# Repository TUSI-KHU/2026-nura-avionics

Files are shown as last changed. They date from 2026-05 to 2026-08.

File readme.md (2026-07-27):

# 2026 NURA Avionics

Teensy 4.1 flight-computer firmware for the 2026 NURA rocket avionics stack.

The current codebase is built around a small cooperative scheduler, explicit state stores, hardware abstraction layers, and a lightweight LoRa telemetry/control protocol. It is still an active integration project: sensor acquisition, LoRa protocol work, mock telemetry, and ground-side receiver tests are in the repository, while flight rules, logging outputs, and final hardware validation are still being tightened.

## Architecture

2026 NURA avionics firmware architecture

Runtime flow:

1. `src/main.cpp` forwards Arduino `setup()` and `loop()` to `FlightControllerApp`.
2. `FlightControllerApp` owns config, state stores, HAL objects, mission tasks, sensor tasks, and the scheduler.
3. `Scheduler` runs fixed task objects cooperatively according to each task's `periodMs()`.
4. Sensor tasks update focused state structs.
5. Mission tasks consume those states for watchdog, FSM, telemetry, and logging behavior.
6. HAL classes are the only layer that should talk directly to board pins, buses, radios, and sensor libraries.

Production task order:

```text
IMUTask -> HighGImuTask -> MagnetometerTask -> BarometerTask -> GNSSTask -> WatchdogTask -> FSMTask -> FlightLogTask -> TelemetryTask -> LoggerTask
```

Mock telemetry task order:

```text
MockTelemetrySourceTask -> WatchdogTask -> FSMTask -> FlightLogTask -> TelemetryTask -> LoggerTask
```

## Current Firmware Scope

- Board target: Teensy 4.1 with Arduino framework through PlatformIO.
- Low-g IMU path: `LSM6DSO32HAL` -> `IMUTask` -> `ImuState`.
- Barometer path: `MPL3115A2HAL` -> `BarometerTask` -> `TelemetryState`.
- GNSS path: `UbloxM6GNSSHAL` -> `GNSSTask` -> `GpsState`.
- High-g IMU path: `H3LIS331DLHAL` -> `HighGImuTask` -> `HighGImuState`.
- Magnetometer path: `LIS3MDLHAL` -> `MagnetometerTask` -> `MagnetometerState`.
- LoRa path: `Sx127xLoRaHAL` plus `TelemetryTask`, targeting the SparkFun
  SPX-18572 / E19-915M30S SX1276 1 W breakout.
- Protocol: fixed-length authenticated NURA V2 Lite frames in `protocol/include/nura_protocol_v1_lite.h`.
- Flight logging: U3 program flash primary plus microSD mirror through `FlightLogTask`, with `.NLG` parsing tools under `log_parser/`.
- Mock path: `MockFlightDataHAL` and `MockTelemetrySourceTask` feed deterministic telemetry for bench protocol tests.

Additional sensor HALs and sketches remain under `src/hal` and `sensor_test` for isolated hardware bring-up.

## LoRa Protocol

The active protocol is documented in `documents/nura_lora_packet_protocol_v1.md`.

V2 Lite keeps only three message classes:

| Message | Direction | Purpose |
| --- | --- | --- |
| `FAST_TLM` | avionics -> ground | high-rate pressure delta, low-g IMU, gyro, battery, status word |
| `GPS_TLM` | avionics -> ground | slower GNSS recovery/navigation telemetry |
| `CONTROL` | bidirectional | uplink commands and downlink ACK responses |

Nominal application rates:

```text
FAST_TLM: 5 Hz
GPS_TLM: 1 Hz
CONTROL: on demand, ACK has priority over telemetry
```

Flight radio defaults currently target the SparkFun SX1276 1 W breakout at
922.3 MHz. `NURA_DEV_SX1278` switches development builds toward the legacy
SX1278/Ra-01 433 MHz bench setup.

## Repository Layout

```text
src/app/        composition root and app configuration
src/core/       scheduler, task API, logger, recoverable-task policy
src/hal/        board, bus, sensor, radio, panic, and log-output adapters
src/sensors/    sensor acquisition tasks
src/missions/   FSM, watchdog, telemetry, logger, and mock source tasks
src/state/      small shared state stores
protocol/       shared NURA V2 Lite authenticated frame codec header
log_parser/     host-side .NLG binary flight-log parser
sender/         standalone avionics-side LoRa protocol test firmware
receiver/       standalone ground-side LoRa protocol test firmware and pair-test tool
test/           embedded diagnostics, replay tests, and host-side checks
documents/      protocol, requirements, schedule exports, and architecture assets
```

## PlatformIO Environments

| Environment | Purpose |
| --- | --- |
| `main` | Teensy 4.1 firmware with the SX1276 breakout |
| `debug` | SX1276 breakout firmware with verbose logging |
| `debug_lora_autoflow` | bench-only SX1276 debug; automatic `SAFE -> ARMED -> LAUNCH`, then hold |
| `main_no_lora` | full application with the radio disabled |
| `debug_no_lora` | verbose application with the radio disabled |

Common commands:

```bash
pio run -e main
pio run -e debug
pio run -e debug_lora_autoflow
pio run -e main_no_lora
pio run -e debug_no_lora
```

`debug_lora_autoflow` is a bench-only build. It inherits the SparkFun
SPX-18572/E19-915M30S SX1276 path, limits the configured radio drive to 2 dBm,
and allows radio-init failure for wiring diagnostics. The FSM synthesizes
`SAFE -> ARMED -> LAUNCH` and then holds at `LAUNCH`; do not use it for flight
and do not connect pyro hardware.

Upload and monitor:

```bash
pio run -e build -t upload
pio device monitor -b 115200
```

The root PlatformIO environments use a custom Teensy upload command that retries
the loader after the common first soft-reboot write failure, so uploads should
work through the normal `pio run ... -t upload` path.

Standalone sender/receiver builds:

```bash
pio run -d sender
pio run -d receiver
```

Two-board LoRa protocol test:

```bash
python3 receiver/tools/run_pair_test.py --duration 20
```

## Development Agreements

Use the shared schedule sheet as the source of truth for deadlines and team coordination. The current firmware direction follows these working agreements:

- Build each hardware path through `HAL -> Task -> State`, then integrate it into the flight app.
- Verify individual sensors with Arduino/PlatformIO sketches before relying on them in the flight controller.
- Keep LoRa as a lossy telemetry and control link, not as the primary raw-data recorder.
- Store high-rate raw flight data locally through U3 program flash and the microSD mirror.
- Validate changes through unit tests, mock tests, and full hardware tests before treating them as flight-ready.
- Keep the ground station decoder aligned with `protocol/include/nura_protocol_v1_lite.h`.

## Safety Notes

- `CONTROL` commands request actions; packet parsing must not directly energize actuators.
- Emergency recovery deployment must remain deduplicated, authenticated, ACKed, and routed through mission logic.
- Frequency, output power, antenna gain, duty cycle, and final channel plan must be checked against competition rules and Korean radio requirements before flight.
- The current code is integration firmware, not a completed flight-certified avionics release.

## License

This project is licensed under the Apache License 2.0. Third-party libraries retain their own licenses.

This repository contains experimental avionics software and documentation. It is provided without warranty and must be independently reviewed, tested, and validated before any flight or safety-critical use.

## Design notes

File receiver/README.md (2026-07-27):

# NURA LoRa Receiver

Ground-side Teensy 4.1 receiver for authenticated NURA V2 Lite telemetry.

Use the `sx1276_ground` environment for the 922.3 MHz SX1276 ground radio.
The default `teensy41` environment remains the 433 MHz development setup.
The SX1276 ground environment fixes the SPI bus to MODE0; automatic mode
probing remains limited to the development environment.
The standalone ground wiring is `CS=10`, `RESET=9`, `DIO0=2`, `RXEN=4`, and
`TXEN=3`; it is intentionally independent of the flight-computer pin map.
The receive-only SX1276 environment drives `RXEN=HIGH` and `TXEN=LOW`. This
polarity is a bench assumption that must be checked against the module
datasheet before enabling ground uplink transmission.

The implementation follows `documents/nura_lora_packet_protocol_v1.md` and the shared protocol header in `protocol/include/nura_protocol_v1_lite.h`.

Default firmware behavior:

1. Decodes FAST_TLM, GPS_TLM, and CONTROL/ACK frames.
2. Prints real avionics sensor telemetry with engineering units:
   - FAST: flight state, status word, pressure delta, low-g acceleration, gyro, battery, health bits, RSSI/SNR.
   - GPS: fix, latitude/longitude, altitude, speed, course, HDOP, satellites, age, RSSI/SNR.
3. Does not transmit recovery/control commands.

Pair-test-only behavior is available in the `pair_test` environment. That build defines `NURA_RECEIVER_AUTO_COMMAND_TEST` and automatically sends FORCE_DEPLOY_RECOVERY followed by the deprecated abort command check. Do not use that environment with flight hardware unless the recovery output path is intentionally inhibited for a bench test.

The Arduino gateway must remain a dumb raw-byte bridge. All decoding and command logic belongs here or in the GCS process.

Build receive-only ground station firmware with:

```sh
pio run -d receiver -e teensy41
```

Upload and monitor receive-only firmware with:

```sh
pio run -d receiver -e teensy41 -t upload
pio device monitor -d receiver -b 115200
```

Two-board protocol test with automatic bench commands:

```sh
python3 receiver/tools/run_pair_test.py --duration 20
```

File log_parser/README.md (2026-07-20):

# NURA Log Parser

`parse_nlg.py` converts NURA binary flight logs into readable CSV and JSON
files. It auto-detects the preallocated microSD block journal, a raw W25Q128
flash dump, or a plain legacy `.NLG` frame stream.

## Usage

```bash
python3 log_parser/parse_nlg.py analysis/program_flash_NURA_LOG_FL008_NLG_20260530_145006.NLG
```

By default it creates `<input_stem>_parsed/` beside the input file. Use
`--out-dir` to choose the destination:

```bash
python3 log_parser/parse_nlg.py input.NLG --out-dir analysis/parsed_log
```

## Outputs

- `frames.csv`: every frame in sequence order, with decoded fields and units.
- `frames.json`: the same decoded frames as JSON.
- `fast_sample.csv`: high-rate IMU/barometer/state samples.
- `slow_sample.csv`: GPS/magnetometer/barometer fault counters.
- `event.csv`: boot, state transition, ground stop, and storage fault events.
- `decision.csv`: state-machine decision traces when present.
- `summary.json`: frame count, sequence range, timestamp range, and output paths.

The parser verifies frame magic, version, payload length, maximum frame size, and
CRC16-CCITT before writing decoded output. For current SD logs it first verifies
the 512-byte block session, sequence and CRC fields. For QSPI dumps it verifies
the 4 KiB sector and 256-byte page headers before reconstructing the logical
frame stream.

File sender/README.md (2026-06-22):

# NURA LoRa V2 Sender Bench Emulator

This folder is reserved for the avionics-side LoRa sender implementation.

The implementation follows `documents/nura_lora_packet_protocol_v1.md` and the shared protocol header in `protocol/include/nura_protocol_v1_lite.h`.

Current firmware behavior:

1. Sends synthetic FAST_TLM at 5 Hz.
2. Sends synthetic GPS_TLM at 1 Hz.
3. Receives CONTROL/CMD.
4. Authenticates and deduplicates commands.
5. Sends CONTROL/ACK for FORCE_DEPLOY_RECOVERY and ABORT_PROPULSION_DEPRECATED.
6. Skips telemetry whenever ACK has priority.

Do not transmit raw C++ structs directly. Encode every integer field explicitly as little-endian bytes.

Build with:

```sh
pio run -d sender
```

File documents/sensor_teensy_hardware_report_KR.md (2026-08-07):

# NURA 2026 센서 및 Teensy 하드웨어 정리 보고서

작성일: 2026-06-26  
대상 코드 기준: `include/board_pinmap.h`, `include/nura_constants.h`, `src/hal/*`, `platformio.ini`, `documents/pinmap_summary.txt`

> 이 문서는 부품 데이터시트/공식 가이드와 현재 펌웨어 핀맵을 대조한 하드웨어 정리 보고서이다. 비행 승인 문서가 아니며, PCB 리비전/실물 회로/커넥터 방향/전원 레일/납땜 상태는 별도 검증이 필요하다.

## 1. 현재 프로젝트 하드웨어 요약

| 분류 | 부품 / 모듈 | 프로젝트 역할 | 현재 인터페이스 | 현재 핀 |
| --- | --- | --- | --- | --- |
| MCU | Teensy 4.1 | 비행 컴퓨터 | USB, GPIO, SPI, I2C, UART, ADC, SDIO/QSPI | PlatformIO `teensy41` |
| 저-g IMU | LSM6DSO32 / LSM6DSOX | 주 IMU, 가속도/자이로 | SPI0 | MOSI D11, MISO D12, SCK D13, CS D10 |
| 고-g 가속도계 | H3LIS331DL | 발사/충격/고가속 로깅 후보 | SPI0 | MOSI D11, MISO D12, SCK D13, CS D0 |
| 자기계 | LIS3MDL | 자기장/방위 후보 | I2C1 | SDA1 D17, SCL1 D16, 주소 `0x1C` |
| 기압계 | MPL3115A2 | 고도/압력 | I2C0 | SDA0 D18, SCL0 D19, 주소 `0x60` |
| GNSS | u-blox M6 / NEO-6M 계열 | 위치/시간/회수 지원 | UART Serial3 | GPS TX -> D15/RX3, GPS RX -> D14/TX3, 9600 baud |
| 비행 LoRa | SparkFun SPX-18572 / E19-915M30S SX1276 1W | 비행체 텔레메트리 | SPI1 + DIO0/RXE/TXE | MISO1 D1, MOSI1 D26, SCK1 D27, NSS D9, RST D24, DIO0 D32, RXE D30, TXE D31 |
| 지상/개발 LoRa | SparkFun SPX-18572 / E19-915M30S SX1276 1W | 지상 수신/개발 테스트 | SPI1 + DIO0/RXE/TXE | 동일 922.3 MHz 핀맵 |
| 전압 센스 | 3S 배터리 분압 | 배터리 전압 텔레메트리 | ADC | D22, 분압비 5.545 |
| 저장장치 | Teensy 내장 microSD | 비행 로그 미러 | SDIO | `BUILTIN_SDCARD` |
| 저장장치 | W25Q128 QSPI NOR flash 후보 | 온보드 로그/검증 저장 | Teensy 4.1 하단 QSPI pads | 16 MB / 128 Mbit 후보 |
| 알림 | Buzzer, LED | 상태/오류 피드백 | GPIO/PWM | Buzzer D2, LED2 D33 |

중요: 현재 소스의 기준은 `include/board_pinmap.h`와 `documents/pinmap_summary.txt`이다. 현재 Pyro 1은 gpio1 D28/gpio2 D29/sense D25, Pyro 2는 gpio1 D38/gpio2 D35/sense D41, 배터리 전압 센스는 D22로 서로 충돌하지 않는다.

## 2. Teensy 4.1

### 핵심 특징

- MCU: NXP i.MX RT1062, 600 MHz급 ARM Cortex-M7 계열 보드.
- I/O: PJRC 공식 페이지 기준 총 55개 신호 핀, 브레드보드에서 쉽게 접근 가능한 핀은 42개.
- 로직 레벨: 디지털 핀은 3.3 V 신호용이며 5 V tolerant가 아니다. VIN/VUSB를 제외한 일반 I/O에 3.3 V 초과를 넣으면 손상 위험이 있다.
- 내장 기능: USB device, USB host pads, Ethernet pads, microSD socket, 하단 QSPI 메모리 패드.
- 프로젝트 빌드: `platformio.ini`에서 `board = teensy41`, `framework = arduino`, 시리얼 모니터 115200 baud.

### 프로젝트에서 쓰는 버스

| 버스 | Teensy 핀 | 프로젝트 사용 |
| --- | --- | --- |
| SPI0 | MOSI D11, MISO D12, SCK D13 | LSM6DSO32/LSM6DSOX, H3LIS331DL, 일부 SX127x 개발 테스트 |
| SPI1 | MISO D1, MOSI D26, SCK D27 | SparkFun SX1276 1W |
| I2C0 / Wire | SDA D18, SCL D19 | MPL3115A2 |
| I2C1 / Wire1 | SDA D17, SCL D16 | LIS3MDL |
| UART3 / Serial3 | RX3 D15, TX3 D14 | u-blox M6 GNSS |
| ADC | D22 | 3S 배터리 전압 분압 |
| SDIO | `BUILTIN_SDCARD` | microSD 비행 로그 |

### 전원 관련 주의사항

- USB와 외부 전원을 동시에 연결할 경우, Teensy 하단의 VIN-VUSB 연결 trace를 자르는 것이 일반적인 보호 방법이다. 이렇게 하면 USB 5 V가 VIN 쪽 회로를 먹이지 않고, 반대로 외부 5 V/VIN이 노트북 USB 포트로 역류하는 위험도 줄어든다.
- 단점: VIN-VUSB trace를 자른 뒤에는 USB 케이블만 꽂아서는 보드가 켜지지 않는다. USB 데이터는 연결되지만, 별도 VIN 전원이 있어야 업로드/시리얼이 동작한다.
- 되돌리려면 잘랐던 pads를 납으로 다시 bridge해야 한다. 현장에서는 trace cut 후 멀티미터 continuity로 VIN-VUSB가 정말 분리됐는지 확인해야 한다.
- 외부 전원 운용 시 권장 방식은 `USB 데이터 + 외부 VIN 전원`을 분리 운용하거나, 쇼트키 다이오드/전원 OR-ing 회로를 사용하는 것이다. 단순 병렬 연결은 노트북과 비행 전원 모두에 나쁘다.
- Teensy 3.3 V 핀은 보드 레귤레이터 출력이다. 많은 센서 breakout에 전원을 공급할 수는 있지만, RF 송신/SD write/센서 inrush가 겹치면 전압 강하와 노이즈가 생길 수 있다. RF/아날로그/센서 전원은 디커플링을 실물에서 확인해야 한다.

### 핀 레벨 주의사항

- Teensy 4.1 GPIO는 3.3 V만 안전하다.
- “Adafruit breakout은 5 V tolerant” 같은 말은 breakout 보드에 level shifter/regulator가 있을 때의 이야기이다. 센서 IC 자체는 대부분 1.8~3.6 V 계열이다.
- 현재 NURA PCB는 모든 센서 VCC를 Teensy 3.3 V rail 기준으로 보는 문서가 있다. 외부 5 V 센서 모듈을 섞으면 I2C/SPI 라인 level이 즉시 문제가 될 수 있다.

## 3. LSM6DSO32 / LSM6DSOX 저-g IMU

### 부품 특징

- 3축 가속도 + 3축 자이로.
- LSM6DSO32 데이터시트 기준 가속도 full-scale: ±4/±8/±16/±32 g.
- 자이로 full-scale: ±125/±250/±500/±1000/±2000 dps.
- I2C, SPI, I3C 계열 인터페이스를 지원한다.
- Adafruit LSM6DSO32 breakout은 VIN regulator와 level shifting이 있어 3 V/5 V MCU와 쓰기 쉽게 만든 보드이다.

### 프로젝트 연결

| 항목 | 값 |
| --- | --- |
| 프로젝트 역할 | 저-g IMU, 자세/가속도/자이로 |
| 현재 통신 | SPI0 |
| SPI 핀 | MOSI D11, MISO D12, SCK D13 |
| CS | D10 |
| INT1/INT2 | 미할당 |
| WHO_AM_I | LSM6DSO32 기대값 `0x6C` |
| HAL | `src/hal/lsm6dso32_hal.cpp`, `src/hal/lsm6dsox_hal.cpp` |
| 현재 task 주기 | 10 ms |

### 펌웨어 설정/동작

- `LSM6DSO32HAL::begin()`은 SPI mode 0~3을 직접 probe해서 WHO_AM_I가 맞는 mode를 찾는다.
- 이후 Adafruit LSM6DS 기반 init을 수행하고 accel/gyro range와 data rate를 설정한다.
- 읽기값은 `m/s^2`, `dps`, 온도 C로 저장된다.
- stationary calibration 함수가 있으며, 기대 중력 방향을 기준으로 accel offset과 gyro bias를 계산한다.

### 실무 주의사항

- LSM6DSO32는 ±32 g까지 가능하지만, 프로젝트 코드/테스트에서 LSM6DSOX bring-up은 ±16 g 설정 예제가 있다. 실제 flight range가 무엇인지 코드 경로별로 확인해야 한다.
- CS가 D10이므로 SPI0의 일반 SS 핀과 겹친다. microSD는 Teensy 내장 SDIO라 괜찮지만, 외부 SPI 장치 추가 시 CS 충돌을 피해야 한다.
- Adafruit breakout은 I2C 주소 jumper가 있다. I2C로 쓸 경우 기본 주소는 보통 `0x6A`, address pin high/jumper 시 `0x6B`이다. 현재 프로젝트는 SPI라 I2C 주소는 사용하지 않는다.
- IMU 축 방향은 breakout 실크와 PCB 장착 방향에 따라 바뀐다. “센서가 정상 응답한다”와 “로켓 좌표계와 축이 맞다”는 다른 문제다. 발사 감지/자세 추정에 쓰려면 X/Y/Z 부호와 로켓 body frame 변환을 별도 문서화해야 한다.
- 보드가 정지 상태일 때 가속도 norm은 약 1 g가 나와야 한다. 하지만 각 축 중 어디에 +1 g가 나타나는지는 장착 방향에 따라 달라진다.
- 자이로 bias는 온도와 시간에 따라 변한다. 발사대 정지 상태에서 boot calibration을 하고, arming 직전 재확인하는 쪽이 안전하다.

## 4. H3LIS331DL 고-g 가속도계

### 부품 특징

- 3축 high-g digital accelerometer.
- ST 데이터시트 기준 full-scale: ±100/±200/±400 g.
- ODR: 0.5 Hz ~ 1 kHz.
- 인터페이스: I2C/SPI.
- 공급 전압: 2.16 V ~ 3.6 V, IO는 저전압 호환.
- 충격 내성은 데이터시트상 10000 g class로 표기된다.

### 프로젝트 연결

| 항목 | 값 |
| --- | --- |
| 프로젝트 역할 | 고가속/충격/발사 이벤트 후보 |
| 현재 통신 | SPI0 |
| SPI 핀 | MOSI D11, MISO D12, SCK D13 |
| CS | D0 |
| INT1/INT2 | 미할당 |
| WHO_AM_I | 기대값 `0x32` |
| HAL | `src/hal/h3lis331dl_hal.cpp` |
| 현재 data rate | Adafruit driver에서 1000 Hz로 설정 |

### 실무 주의사항

- ±100/200/400 g 센서는 작은 흔들림/정지 1 g 측정에서는 저-g IMU보다 거칠고 noisy하다. “발사 충격을 안 잘라먹는 센서”이지 “정밀 자세 센서”가 아니다.
- SPI0를 LSM6DSO32와 공유한다. 각 센서 CS는 idle HIGH가 유지되어야 한다. 부팅 중 한 CS가 floating이면 두 SPI 장치가 동시에 MISO를 물고 버스가 깨질 수 있다.
- 현재 INT 핀이 미할당이라 data-ready interrupt 기반 샘플링은 하지 않는다. 고속 이벤트를 놓치지 않으려면 ODR, polling 주기, FIFO/interrupt 사용 여부를 별도 검증해야 한다.
- 고-g 센서를 발사 감지에 쓰려면 threshold 출처가 반드시 필요하다. 임의 g값을 넣으면 flight logic 안전 규칙에 위배된다.

## 5. LIS3MDL 자기계

### 부품 특징

- 3축 digital magnetometer.
- ST 데이터시트 기준 full-scale: ±4/±8/±12/±16 gauss.
- I2C standard/fast mode와 SPI를 지원한다.
- Adafruit LIS3MDL breakout은 STEMMA QT/Qwiic I2C 연결과 level shifting/support 회로를 제공한다.

### 프로젝트 연결

| 항목 | 값 |
| --- | --- |
| 프로젝트 역할 | 자기장/방위 후보 |
| 현재 통신 | I2C1 / Wire1 |
| 핀 | SDA1 D17, SCL1 D16 |
| 주소 | `0x1C` |
| 주소 설정 | DO/SDO 또는 AD1 계열 address pin을 GND/open 쪽으로 둔 상태 |
| HAL | `src/hal/lis3mdl_hal.cpp` |
| task 주기 | 100 ms |

### 실무 주의사항

- LIS3MDL Adafruit guide 기준 address jumper를 high/bridge하면 주소가 `0x1C`에서 `0x1E`로 바뀐다. 현재 펌웨어는 `0x1C` 고정이므로 jumper 상태가 중요하다.
- I2C mode 강제를 위해 breakout의 CS를 3.3 V에 묶는 구성이 문서에 적혀 있다. CS가 떠 있으면 SPI/I2C mode 판단이 불안정해질 수 있다.
- 자기계는 로켓 내부에서 가장 쉽게 오염되는 센서다. 배터리, 전류 루프, 모터 케이스, 나사, pyro 배선, RF coax 근처에서 hard-iron/soft-iron error가 커진다.
- boot-only calibration으로는 부족하다. 완성된 avionics stack을 실제 장착 상태로 돌려서 hard/soft iron calibration을 해야 한다.
- 발사 중 큰 전류가 흐르는 순간에는 자기계 heading이 튈 수 있다. 비행 상태 전이에 직접 쓰기보다 로그/후처리/보조 heading으로 보는 것이 안전하다.

## 6. MPL3115A2 기압계

### 부품 특징

- 절대압 기반 pressure/altimeter sensor.
- NXP 데이터시트 기준 operating pressure range: 20 kPa ~ 110 kPa.
- calibrated pressure range: 50 kPa ~ 110 kPa.
- 온도 출력 포함, I2C digital interface.
- altitude output resolution은 0.1 m class로 홍보되지만, 로켓에서는 pressure port, 동압, 진동, 온도, 필터링이 실제 성능을 좌우한다.
- 2026년 기준 NXP 페이지는 MPL3115A2/MPL3150A2를 discontinued로 표시하고, 신규 설계에는 MPL3115A2S/MPL3150A2S를 권장한다.

### 프로젝트 연결

| 항목 | 값 |
| --- | --- |
| 프로젝트 역할 | 고도/압력 |
| 현재 통신 | I2C0 / Wire |
| 핀 | SDA0 D18, SCL0 D19 |
| 주소 | `0x60` only |
| HAL | `src/hal/mpl3115a2_hal.cpp` |
| task 주기 | 50 ms |
| conversion timeout | 50 ms |
| 유효 압력 범위 | 20000 Pa ~ 110000 Pa |

### 펌웨어 설정/동작

- HAL은 BAROMETER mode를 사용한다.
- `CTRL_REG1`은 프로젝트 상수 `kFastBarometerCtrlReg1 = 0x00`으로 BAR mode, OS1 쪽 빠른 변환을 사용한다.
- non-blocking `poll()` 경로는 conversion 시작, 완료 확인, timeout 처리를 분리한다.
- pad ground baseline을 평균 압력으로 잡고, 상대 고도는 기준 압력 대비 barometric formula로 계산한다.

### 실무 주의사항

- 주소가 `0x60` 하나뿐이라 같은 버스에 `0x60` 고정 장치를 추가하면 충돌한다. 현재 MPL3115A2는 I2C0 단독이라 괜찮다.
- I2C pull-up은 버스당 한 쌍만 적절한 값으로 두는 것이 좋다. 여러 breakout의 10 k pull-up이 병렬로 많이 붙으면 effective resistance가 낮아져 rise time/전류가 바뀐다.
- 로켓 기압계는 센서 자체보다 pressure port 설계가 중요하다. 동압을 직접 맞으면 apogee detection이 흔들린다. 정압 포트 위치, 포트 수, 내부 volume, vent hole burr를 검사해야 한다.
- MPL3115A2 온도값은 보조 참고로만 써야 한다. 센서 내부 보상용 온도 성격이 강하며, 외기 온도계처럼 믿으면 안 된다.
- 부품 수급상 discontinued 이슈가 있으므로 새 PCB 리비전에서는 대체품 검토가 필요하다. 펌웨어 HAL은 `MPL3115A2S` 호환 여부를 확인하기 전까지 가정하면 안 된다.

## 7. u-blox M6 / NEO-6M GNSS

### 부품 특징

- u-blox 6 positioning engine 기반 GPS 모듈.
- 프로젝트 문서상 GY-GPS6MV2 / NEO-6M 계열 breakout 사용.
- u-blox 공식 문서는 NEO-6 시리즈가 miniature NEO form factor의 GPS module이며 NMEA/UBX protocol을 지원한다고 설명한다.
- 흔한 GY-NEO6MV2 모듈은 ceramic patch antenna, backup battery, EEPROM이 붙어 있지만, clone/제조사별 회로가 달라 전원/level 조건을 실물 확인해야 한다.

### 프로젝트 연결

| 항목 | 값 |
| --- | --- |
| 프로젝트 역할 | 위치/고도/속도/course/HDOP/satellites 텔레메트리 |
| 현재 통신 | UART Serial3 |
| 핀 | GPS TX -> Teensy RX3 D15, GPS RX -> Teensy TX3 D14 |
| baud | 9600 |
| parser | TinyGPSPlus |
| task 주기 | 50 ms |
| poll byte budget | 128 bytes |
| fix fresh 기준 | 2000 ms |

### 실무 주의사항

- GPS TX와 MCU RX는 교차 연결이다. GPS TX -> Teensy RX3 D15, GPS RX -> Teensy TX3 D14가 맞다.
- Teensy는 3.3 V UART라 NEO-6M IC와 전압 레벨이 맞는다. 5 V Arduino 예제처럼 막 연결하는 습관을 가져오면 GPS RX에 과전압이 들어갈 수 있다.
- GY-NEO6MV2 breakout은 “VCC 3~5 V 가능”으로 팔리는 경우가 많지만, 그것은 보드 regulator 이야기다. UART RX가 5 V tolerant인지 여부는 모듈 회로에 따라 다르다.
- patch antenna는 하늘을 봐야 한다. avionics bay 내부, carbon fiber, 금속 bulkhead, 배터리 아래에서는 fix 시간이 크게 늘거나 fix가 안 잡힌다.
- LED blinking은 보통 fix indication이지만 모듈마다 의미가 다를 수 있다. 펌웨어에서는 NMEA checksum/fix age/satellites/HDOP를 보고 판단해야 한다.
- 비행 중 GNSS altitude는 barometer보다 느리고 지연/점프가 있으므로 apogee 같은 빠른 상태 전이에 직접 쓰면 안 된다.

## 8. SparkFun SPX-18572 / E19-915M30S SX1276 1W LoRa

### 부품 특징

- SparkFun SPX-18572는 E19-915M30S 기반 SX1276 1W LoRa breakout이다.
- 모듈 RF 전원은 5 V(권장 4.75~5.5 V), SPI/GPIO 제어 신호는 3.3 V다.
- SX1276 레지스터 인터페이스와 외부 RXE/TXE RF switch를 사용한다.
- 모듈 데이터시트 기준 송신 전류는 약 630 mA이며, 안테나 없이 송신하면 안 된다.

### 프로젝트 연결

| 항목 | 값 |
| --- | --- |
| 프로젝트 역할 | 비행 텔레메트리 |
| 현재 통신 | SPI1 |
| SPI 핀 | MISO1 D1, MOSI1 D26, SCK1 D27 |
| NSS | D9 |
| RST | D24 |
| DIO0 | D32 |
| RXE | D30, active-high |
| TXE | D31, active-high |
| 주파수 | 922.3 MHz |
| SPI clock | 현재 상수 250 kHz bring-up setting |
| LoRa 설정 | SF7, BW 125 kHz, CR 4/5, preamble 8, sync word `0x12`, TX power 2 dBm |
| RF path idle | RXE=0, TXE=0 |

### 펌웨어 설정/동작

- `src/hal/sx127x_lora_hal.cpp`가 SPI1, RST, DIO0, RXE/TXE를 직접 제어한다.
- 수신은 RXE=1/TXE=0, 송신은 RXE=0/TXE=1이며 패킷 완료 후 수신으로 돌아온다.
- 현재 production 기본값은 `downlinkOnly = false`이며, 송신 완료 후 RX로 복귀해
  인증된 `ARM_FLIGHT` 업링크를 수신한다.

### 실무 주의사항

- RXE/TXE polarity는 SparkFun/E19 module definition에 맞춰 active-high로 구현되어 있다.
- 5 V RF rail은 Teensy 3.3 V rail과 분리하고, 전류 제한과 충분한 디커플링을 확보해야 한다.
- 2 dBm은 SX1276 core drive setting이며, EIRP/출력은 안테나·PA·규정까지 포함해 별도 측정해야 한다.
- 922.3 MHz 운용은 지역 규정/대회 규정/안테나 대역과 일치해야 한다. 915 MHz 안테나가 922.3 MHz에서 충분히 맞는지도 VNA 또는 range test로 확인해야 한다.
- RF 송신 중 전류 피크가 생긴다. 센서 3.3 V rail과 RF PA 전원이 같은 경로면 IMU/baro 노이즈와 brownout을 확인해야 한다.

## 9. SX1276 지상 및 개발 LoRa

### 부품 특징

- SparkFun SPX-18572 / E19-915M30S는 915 MHz 대역 SX1276과 1 W 외부 PA/LNA를 사용한다.
- SX1276 계열은 SPI + reset + DIO0 interrupt와 외부 RXE/TXE switch를 사용한다.

### 프로젝트 연결

| 항목 | 값 |
| --- | --- |
| 프로젝트 역할 | 지상 수신기 / 개발 테스트 |
| receiver env | `sx1276_ground`에서 922.3 MHz ground radio |
| SparkFun 핀 | NSS D9, RST D24, DIO0 D32, RXE D30, TXE D31 |
| 라이브러리 | sender/receiver 일부는 Sandeep Mistry LoRa, 메인은 RadioLib |

### 실무 주의사항

- RA-01/SX1278 433 MHz 모듈과 SX1276 915/920 MHz 모듈은 같은 LoRa 계열이라도 RF front-end와 matching이 다르다. 주파수만 코드로 바꿔서 쓰면 안 된다.
- SX127x DIO0는 RX done/TX done interrupt로 자주 쓰인다. DIO0 미연결이면 polling 또는 timeout이 필요하다.
- 3.3 V logic 장치다. 5 V Arduino와 직접 연결하는 예제는 Teensy에는 필요 없지만, 반대로 Teensy 주변에 5 V 장치가 있으면 LoRa 핀 과전압을 조심해야 한다.
- 안테나 없이 송신하면 PA 손상 가능성이 있다. 아주 낮은 출력 bench라도 dummy load/안테나 연결을 기본으로 해야 한다.

## 10. 배터리 전압 센스

### 프로젝트 연결

| 항목 | 값 |
| --- | --- |
| 역할 | 3S pack voltage telemetry |
| 핀 | D22 analog input |
| ADC 기준 | 3.3 V |
| ADC resolution | 10 bit |
| 분압비 | pack voltage / 5.545 |
| 12.6 V 예상 ADC 입력 | 약 2.2723 V |
| 11.1 V 예상 ADC 입력 | 약 2.0018 V |
| 정상 raw 범위 | 약 620~704 |
| 유효 pack 범위 | 6000~14000 mV |

### 실무 주의사항

- 3S LiPo full charge 12.6 V가 ADC에 2.27 V로 들어가므로 3.3 V 기준에서는 여유가 있다.
- 저항 tolerance 때문에 실제 분압비는 5.545에서 벗어난다. 멀티미터로 pack voltage와 ADC raw를 동시에 찍어 calibration해야 한다.
- ADC 입력에 너무 큰 source impedance를 쓰면 Teensy ADC sample-and-hold가 충분히 충전되지 않아 값이 흔들릴 수 있다. 분압 저항값과 필터 capacitor를 회로에서 확인해야 한다.
- 현재 펌웨어는 raw를 mV로 환산하고 6~14 V 밖이면 invalid로 본다. invalid/stale은 telemetry에서 0으로 내려갈 수 있다.
- 배터리 음극과 Teensy GND가 확실히 공통이어야 한다. 공통 GND 없이 분압 신호만 넣으면 ADC 입력 보호 다이오드로 이상 전류가 흐를 수 있다.

## 11. microSD 및 W25Q128 QSPI flash

### microSD

- Teensy 4.1 내장 microSD socket은 SDIO 경로를 사용한다.
- 프로젝트는 flight log mirror storage에 microSD를 사용한다.
- D34~D39 계열은 Teensy SDIO 관련 핀으로 쓰일 수 있으므로, 하단/내장 SD 관련 핀과 pyro/main 출력 핀의 충돌 여부를 PCB 리비전마다 확인해야 한다.

### W25Q128 QSPI NOR flash 후보

- Winbond W25Q128JV는 128 Mbit, 즉 16 MB class 3 V serial flash이다.
- Dual/Quad SPI/QPI 계열을 지원하며, Teensy 4.1 하단 QSPI flash pads에 납땜하는 후보로 테스트 코드가 있다.
- 프로젝트 테스트는 LittleFS QSPIFlash로 mount/format/write/read 검증을 수행하고, 예상 용량을 16 MB로 둔다.

### 실무 주의사항

- Teensy 4.1 하단에는 PSRAM/flash용 QSPI pads가 있다. PJRC 공식 설명에 따르면 작은 pads는 PSRAM 위치, 큰 pads는 특정 flash chip에 사용할 수 있다.
- QSPI flash 납땜은 육안상 붙어 보여도 corner pin open/bridge가 흔하다. JEDEC ID read, LittleFS format, 반복 write/read로 검증해야 한다.
- NOR flash erase/write는 읽기보다 훨씬 느리고 blocking 구간이 생긴다. flight scheduler에 직접 write하면 sensor task jitter가 생길 수 있다.
- microSD와 QSPI flash를 동시에 쓰는 구조에서는 “RAM buffer -> 낮은 우선순위 drain” 패턴이 맞다. 현재 프로젝트도 RAM buffer/drain 상수를 둔다.

## 12. Buzzer, LED, Pyro 관련 하드웨어 메모

센서는 아니지만 bring-up과 안전 확인에서 중요하다.

| 항목 | 현재 핀 / 상태 |
| --- | --- |
| Buzzer | D2 |
| LED1 / LED2 / status | D34 / D33 / D33 |
| Pyro 1 / Drogue | D28, D29, sense D25 |
| Pyro 2 / Main | gpio1 D38, gpio2 D35, sense D41 |
| Pyro real output | `NURA_ENABLE_PYRO_OUTPUTS` 없으면 dry-run |

주의:

- Pyro 출력은 패킷 수신, 디버그 명령, raw state assignment에서 직접 energize하면 안 된다.
- MOSFET/TC4452 driver 주변은 bench에서 LED/저항 dummy load/scope로 먼저 확인하고, e-match는 최후 단계에 연결해야 한다.
- D35/D38/D41 같은 Teensy 하단/특수 핀은 soldering 접근성과 SDIO/QSPI/보드 리비전 영향을 반드시 확인해야 한다.

## 13. 통합 bring-up 체크리스트

### 전원/보호

- VIN-VUSB cut 여부 결정: 외부 전원 + USB 디버그를 같이 쓸 비행체라면 cut 권장.
- cut 후 continuity 확인: VIN과 VUSB 사이가 open인지 멀티미터로 확인.
- USB만으로 업로드해야 하는 상황이면 VIN 외부 전원을 같이 공급하거나 cut을 복구해야 한다.
- 모든 센서 VCC가 3.3 V인지, 5 V tolerant breakout인지, IC 직접 연결인지 구분.
- 공통 GND 확인.
- RF 송신/SD write/pyro dummy load 시 3.3 V rail droop 측정.

### I2C

- I2C0 scanner: MPL3115A2 `0x60`.
- I2C1 scanner: LIS3MDL `0x1C`.
- 각 버스 pull-up이 과도하게 병렬로 붙지 않았는지 확인.
- LIS3MDL address jumper가 `0x1C` 위치인지 확인.

### SPI

- SPI0: LSM6DSO32 CS D10, H3LIS331DL CS D0 각각 WHO_AM_I 확인.
- SPI1: SX1262 NSS D9, DIO1 D31, BUSY D32 level 확인.
- 모든 SPI CS는 boot/reset 중 idle HIGH 유지.
- LoRa 송신 전 안테나/dummy load 연결.

### 센서 sanity

- LSM6DSO32: 정지 상태 accel norm 약 1 g, gyro near zero, WHO_AM_I `0x6C`.
- H3LIS331DL: WHO_AM_I `0x32`, 정지 1 g 방향 확인, range 설정 확인.
- MPL3115A2: 지상 압력 80~110 kPa 범위, baseline 생성 후 고도 0 m 근처.
- LIS3MDL: 값 finite, 주변 자석/전류에 따른 saturation 확인.
- GNSS: NMEA checksum pass 증가, satellites/HDOP/fix age 확인.
- 전압 센스: 실제 pack voltage와 telemetry mV 비교.

## 14. 권장 후속 작업

1. `test/sensor_test/README.md`의 오래된 Pyro pin 기록을 현재 핀맵에 맞게 수정한다.
2. 실제 PCB schematic에서 SX1262 `RXE`, `TXEN`, `NRESET`, `DIO2`, `DIO3/TCXO` 연결 여부를 확정한다.
3. LSM6DSO32/H3LIS331DL 축 방향을 로켓 body frame 기준으로 문서화한다.
4. MPL3115A2 discontinued 이슈 때문에 MPL3115A2S 또는 다른 기압계 후보를 부품 수급 관점에서 검토한다.
5. LIS3MDL hard/soft iron calibration 절차와 저장 위치를 정한다.
6. VIN-VUSB cut 적용 여부를 avionics assembly 절차서에 넣는다.
7. LoRa 922.3 MHz 안테나 matching/range test 결과를 별도 RF 검증 문서로 남긴다.

## 15. 주요 웹 출처

- PJRC Teensy 4.1 공식 페이지: https://www.pjrc.com/store/teensy41.html
- PJRC 외부 전원/USB 분리 가이드: https://www.pjrc.com/teensy/external_power.html
- Adafruit LSM6DSOX/ISM330DHC/LSM6DSO32 guide: https://learn.adafruit.com/lsm6dsox-and-ism330dhc-6-dof-imu
- ST LSM6DSO32 datasheet: https://www.st.com/resource/en/datasheet/lsm6dso32.pdf
- Adafruit H3LIS331/LIS331 guide: https://learn.adafruit.com/adafruit-h3lis331-and-lis331hh-high-g-3-axis-accelerometers
- ST H3LIS331DL datasheet: https://www.st.com/resource/en/datasheet/h3lis331dl.pdf
- Adafruit LIS3MDL guide: https://learn.adafruit.com/lis3mdl-triple-axis-magnetometer
- ST LIS3MDL datasheet: https://www.st.com/resource/en/datasheet/lis3mdl.pdf
- NXP MPL3115A2 product page: https://www.nxp.com/products/MPL3115A2
- NXP MPL3115A2 datasheet: https://www.nxp.com/docs/en/data-sheet/MPL3115A2.pdf
- u-blox NEO-6 datasheet: https://content.u-blox.com/sites/default/files/products/documents/NEO-6_DataSheet_%28GPS.G6-HW-09005%29.pdf
- u-blox 6 Receiver Description / Protocol Specification: https://content.u-blox.com/sites/default/files/products/documents/u-blox6_ReceiverDescrProtSpec_%28GPS.G6-SW-10018%29_Public.pdf
- Semtech SX1261/2 datasheet mirror: https://cdn.sparkfun.com/assets/6/b/5/1/4/SX1262_datasheet.pdf
- Semtech SX1276/77/78/79 datasheet mirror: https://www.mouser.com/datasheet/2/761/sx1276-1278113.pdf
- Winbond W25Q128JV product page: https://www.winbond.com/hq/new-online-purchasing-guide/index.html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

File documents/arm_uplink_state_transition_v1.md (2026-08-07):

# Authenticated ARM Uplink and SAFE-to-ARMED Transition

Status: implemented for software integration; radio-pair hardware verification is still required before flight.

## Purpose

The production flight controller must remain in `SAFE` after initialization until
the ground station sends an authenticated, fresh `ARM_FLIGHT` command. Packet
parsing never writes the flight state directly. `TelemetryTask` validates and
queues the request, and `FlightStateMachineTask` remains the sole owner of the
`SAFE -> ARMED` transition.

ARM is a state-transition request only. It does not energize drogue or main pyro
outputs and does not relax abort, sensor, continuity, battery, or physical arming
interlocks.

## Wire Contract

The command uses the existing fixed 24-byte CONTROL payload and 43-byte frame.
No packet length or authentication input changes.

| CONTROL offset | Size | ARM value | Meaning |
| ---: | ---: | ---: | --- |
| 0 | 1 | `0x01` | `CONTROL_CMD` |
| 1 | 1 | `0x04` | `COMMAND_ARM_FLIGHT` |
| 2 | 2 | variable LE | Logical command sequence |
| 4 | 4 | variable LE | Nonce |
| 8 | 4 | non-zero LE | Avionics `millis()` expiry, in ms |
| 12 | 2 | `1` signed LE | Expected source state, `FLIGHT_SAFE` |
| 14 | 2 | `2` signed LE | Requested target state, `FLIGHT_ARMED` |
| 16 | 8 | variable | Existing CONTROL SipHash tag |

The frame direction domain is `UPLINK(0x55)`. Frame CRC, frame authentication,
and CONTROL authentication use the existing NURA V2 Lite rules.

Public bench-key golden vector:

```text
frame_seq     = 0x1234
command_seq   = 0x3344
nonce         = 0xA1B2C3D4
validUntilMs  = 54321

aa 55 23 41 52 55 4e 34 12 01 04 44 33 d4 c3 b2
a1 31 d4 00 00 01 00 02 00 cf 9d 6d 96 41 a0 11
0a 13 d5 1b 51 d9 de 6e cd d2 3d
```

## Inputs And Sources

| Input | Unit | Required value | Source |
| --- | --- | --- | --- |
| Frame/control auth | bytes | Existing tags must verify | NURA V2 Lite protocol |
| `validUntilMs` | ms since avionics boot | Non-zero and not expired | GCS handoff contract; GCS uses latest FAST boot time plus 3000 ms |
| `param0` | state ID | `FLIGHT_SAFE(1)` | Stable state enum/wire contract |
| `param1` | state ID | `FLIGHT_ARMED(2)` | Stable state enum/wire contract |
| Current state | enum | Exactly `State::SAFE` | Shared `FlightState`, owned by FSM |
| Abort status | boolean | Inactive | Shared `AbortState`, owned by safety/watchdog path |
| Pending transition | boolean/seq | No ARM or bench-reset request/ACK pending | Shared request state and telemetry ACK state |

There is no sensor threshold in this decision. The 3000 ms GCS validity window
is a team interface decision, not a sensor-derived flight threshold. Avionics
only enforces the transmitted non-zero deadline using wrap-safe signed time
comparison.

## Processing And State Ownership

```text
LoRa RX
  -> frame length, CRC, direction, vehicle ID, frame auth
  -> CONTROL decode and CONTROL auth
  -> expiry and duplicate checks
  -> ARM format/state/abort/pending checks
  -> queue FlightState.armRequested and ACK_ACCEPTED
  -> FSM consumes request on its next tick
  -> transitionTo(ARMED), including onEnter(ARMED)
  -> record armExecuted and matching sequence
  -> queue ACK_EXECUTED with state_after=FLIGHT_ARMED
```

`ACK_EXECUTED/RESULT_OK` is allowed only when the matching request sequence has
been executed and the current state is actually `ARMED`. A duplicate command is
not re-queued; it receives `ACK_DUPLICATE`, while the original deferred EXECUTED
ACK remains pending.

## Allowed And Forbidden States

| Current state | Result |
| --- | --- |
| `SAFE`, abort inactive, no transition pending | Request accepted |
| `INIT`, `ARMED`, `LAUNCH`, `COAST`, `APOGEE`, `DROGUE`, `DEPLOY`, `GROUND`, `FAULT` | `ACK_REJECTED / RESULT_BAD_STATE / REJECT_STATE_REJECTED` |
| `SAFE` with abort active | Same BAD_STATE rejection |

Production `SAFE` has no automatic transition or timeout fallback. If ARM is
rejected, the controller remains in `SAFE`; the operator must clear the cause
and issue a new authenticated command with a new valid deadline. Bench-only
`NURA_BENCH_FSM_AUTOFLOW` and serial-step builds retain their explicitly gated
test transitions.

## Failure Modes

| Failure | Behavior |
| --- | --- |
| CRC/frame auth invalid | Drop frame; do not trust command identity enough to ACK |
| CONTROL auth invalid | Reject with `AUTH_FAILED` |
| Deadline expired | Reject with `EXPIRED` |
| Deadline zero or state parameters wrong | Reject with `BAD_FORMAT` |
| State not SAFE, abort active, or request conflict | Reject with `BAD_STATE` |
| Abort becomes active after ACCEPTED but before FSM consumption | Cancel request, remain SAFE, send deferred `REJECTED/BAD_STATE`; never execute later |
| Exact command retransmitted | Send DUPLICATE; do not re-execute or erase original pending EXECUTED ACK |
| ACK queue temporarily full | Keep deferred completion pending and retry on later telemetry ticks |
| Radio unavailable | State cannot be remotely armed; production remains SAFE |

## Pyro Invariant

Neither ARM packet handling nor `onEnter(State::ARMED)` calls `setDrogue()`,
`setMain()`, or changes pyro GPIO. The FSM replay test records the pyro HAL calls
and requires zero ON calls during both successful ARM and abort-race rejection.
Physical arming hardware remains an independent energetic inhibit.

## Implementation Map

| Responsibility | File |
| --- | --- |
| Command ID and wire types | `protocol/include/nura_protocol_v1_lite.h` |
| ARM validation policy | `src/missions/telemetry/arm_command_policy.h` |
| Authentication, deduplication, queueing, ACKs | `src/missions/telemetry/telemetry_task.cpp` |
| Request/execution/rejection handshake | `src/state/flight_state.h` |
| Sole state transition and abort-race cancellation | `src/missions/flight/fsm_task.cpp` |
| Production RX intent | `include/nura_constants.h` (`kFlightDownlinkOnly=false`) |

## Verification

Board-free acceptance checks:

```bash
python3 test/protocol/run_protocol_tests.py
python3 test/telemetry/run_arm_uplink_tests.py
pio run -e main
pio run -e debug
```

The protocol test decodes and re-encodes the golden vector byte-for-byte. ARM
policy tests cover zero expiry, incorrect source/target, all non-SAFE states,
abort, and pending-request conflicts. The host telemetry flow test executes the
real `TelemetryTask` and FSM with a fake radio to verify ACCEPTED, eight exact
retries as DUPLICATE, deferred EXECUTED, abort-race REJECTED, one transition,
no pyro energization, and FAST/GPS resumption after ACK traffic.

Required hardware integration before flight:

1. Confirm FAST remains periodic while the radio returns to RX after every TX.
2. Send the golden-equivalent provisioned ARM command from the actual GCS.
3. Observe `ACK_ACCEPTED(SAFE)` followed by `ACK_EXECUTED/OK(ARMED=2)`.
4. Retransmit the same frame eight times at 250 ms and verify one transition.
5. Repeat with abort active and verify SAFE plus REJECTED, with pyro outputs low.

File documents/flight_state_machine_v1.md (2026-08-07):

# NURA Flight State Machine V1

Status: Draft for first FSM implementation  
Target vehicle: 2026 NURA avionics  
Target controller: Teensy 4.1  

This document defines the currently agreed first implementation of the NURA
flight state machine. It intentionally excludes high-rate logging and detailed
sensor fault policy; those are tracked as TODO items for later work.

## Scope

Included in this version:

- State names and sequential enum order.
- Entry actions.
- Periodic actions.
- Timeouts and fallback transitions.
- Transition conditions from the previous state.
- Real-time apogee prediction using a nine-sample quadratic fit.
- Uplink forced recovery deployment as an FSM-owned request path.
- Barometer sample rejection and first degraded barometer fault policy.
- Main deployment at 200 m AGL with a barometer-fault-only six-second fallback.
- High-g / low-g acceleration source fallback for launch and burnout detection.
- Constants that must be represented in code, even if their final values are
  still team-tunable.

Excluded from this version:

- Detailed post-flight log extraction tooling.
- Detailed non-barometer sensor fault policy.
- Hardware-in-the-loop replay with real recorded flight logs.

## Global Operating Assumptions

- After `INIT`, sensor acquisition tasks run continuously in every state.
- The FSM reads the latest shared sensor/state values; it does not directly
  perform sensor bus reads.
- Boot waits for board power and bus settle time before task initialization.
  Individual sensor `begin()` calls retry before the task declares init failure.
- Flight logging records state transitions and decision traces, but the FSM
  itself still owns the recovery decisions.
- Barometer fault fallback is implemented for apogee/main decisions. High-g
  acceleration fallback is implemented only as a degraded launch/burnout backup.
  Broader sensor degraded-mode policy is still TODO.
- Launch and burnout detection use a single scalar acceleration norm in g.
  Low-g is the primary source; high-g is used only when low-g is unavailable,
  stale, or non-finite.
- Constants and thresholds must live in code as named constants, not inline
  literals.
- `APOGEE` is a real state in this design. It represents the drogue pyro
  sequence state, not merely an instantaneous event.
- Production avionics remains in `SAFE` until an authenticated, unexpired
  `ARM_FLIGHT` uplink requests exactly `SAFE(1) -> ARMED(2)`. Telemetry queues
  the request; only the FSM performs the transition. The external physical
  pyro/arming hardware remains the independent energetic safety inhibit.
- A boot/init failure intentionally remains a hard stop, but it must be audible
  and USB-friendly so the board does not look electrically dead during bench
  debugging.
- microSD is init-critical. Missing media, mount failure, directory creation
  failure, file creation failure, or preallocation failure prevents completion
  of `FlightControllerApp::setup()`, even if program flash is available.

## Enum Order

State IDs are sequential and must remain stable once telemetry or log parsing
depends on them.

| ID | Enum name | Meaning |
| ---: | --- | --- |
| 0 | `INIT` | Boot, sensor initialization, and calibration |
| 1 | `SAFE` | Powered but inactive safety state |
| 2 | `ARMED` | Armed, waiting for launch detection |
| 3 | `LAUNCH` | Launch detected, motor burn / high-acceleration phase |
| 4 | `COAST` | Burnout detected, coasting toward apogee |
| 5 | `APOGEE` | Apogee decision reached; drogue pyro sequence active |
| 6 | `DROGUE` | Drogue sequence complete; waiting for main deploy condition |
| 7 | `DEPLOY` | Main pyro sequence active / main deployed transition state |
| 8 | `GROUND` | Flight complete / recovered or assumed landed |
| 9 | `FAULT` | Fault hold state |

## Constants

Initial implementation constants:

| Constant | Initial value | Unit | Source / note |
| --- | ---: | --- | --- |
| `BOARD_POWER_SETTLE_DELAY_MS` | `5000` | ms | Team bench decision; allow the new board sensors, SD, and program flash logger to power up before bus/device init |
| `BUS_SETTLE_DELAY_MS` | `250` | ms | Team bench decision; allow SPI/I2C bus pins and pullups to settle before sensor `begin()` calls |
| `PANIC_FAILURE_TONE_FREQUENCY_HZ` | `3200` | Hz | Team bench decision; audible init-failure alarm |
| `PANIC_DEFAULT_FAILURE_BEEPS` | `2` | beeps | Team decision; unknown or non-storage/non-LoRa init failure |
| `PANIC_LORA_FAILURE_BEEPS` | `3` | beeps | Team decision; LoRa/telemetry init failure |
| `PANIC_STORAGE_FAILURE_BEEPS` | `4` | beeps | Team decision; SD/program-flash/storage init failure if storage becomes init-critical |
| `PANIC_FAILURE_REPEAT_PAUSE_MS` | `1000` | ms | Team decision; quiet gap between audible error-code groups |
| `SENSOR_INIT_RETRY_ATTEMPTS` | `5` | attempts | Team bench decision; retry device `begin()` before treating init as failed |
| `SENSOR_INIT_RETRY_DELAY_MS` | `150` | ms | Team bench decision; delay between sensor init retries |
| `SD_INIT_RETRY_ATTEMPTS` | `20` | attempts | Team bench decision; SD is init-critical, but current PCB/card stack can need extra settle time |
| `SD_INIT_RETRY_DELAY_MS` | `250` | ms | Team bench decision; delay between SD mount/directory retries |
| `ACCEL_FALLBACK_MAX_SAMPLE_AGE_MS` | `50` | ms | Freshness bound for high-g/low-g acceleration samples used by launch and burnout detection |
| `LAUNCH_ACCEL_THRESHOLD_G` | `2.0` | g | Team decision, based on 2025 acceleration-norm logs |
| `LAUNCH_CONFIRM_SAMPLES` | `4` | samples | Team decision; consecutive selected-acceleration samples |
| `BURNOUT_ACCEL_THRESHOLD_G` | `1.0` | g | Team decision; selected acceleration norm below this enters coast |
| `BURNOUT_CONFIRM_SAMPLES` | `4` | samples | Team decision; consecutive selected-acceleration samples |
| `APOGEE_FIT_WINDOW_SAMPLES` | `9` | samples | Barometer sliding-window quadratic fit |
| `APOGEE_PREDICTION_HISTORY_SAMPLES` | `5` | samples | Recent valid apogee predictions used by `plus2sigma5` |
| `APOGEE_CONFIRM_SAMPLES` | `3` | samples | Consecutive valid apogee predictions before deployment |
| `APOGEE_MIN_FLIGHT_TIME_MS` | `8000` | ms | Reject prediction and descent backup before this flight time |
| `APOGEE_MAX_PREDICT_AHEAD_S` | `1.0` | s | Reject apogee predictions too far in the future |
| `APOGEE_DEPLOY_ALT_MARGIN_M` | `3.0` | m | Trigger when predicted apogee is this close |
| `APOGEE_MAX_ALT_MARGIN_M` | `20.0` | m | Reject predictions too far above current altitude |
| `APOGEE_MIN_CURVATURE` | `0.05` | m/s^2-scale | Reject near-linear fits; fit coefficient `a` must be `< -0.05` |
| `APOGEE_MAX_CURVATURE` | `120.0` | m/s^2-scale | Reject unrealistically sharp fitted curves; fit coefficient `a` must be `> -120` |
| `APOGEE_MAX_FIT_RMSE_M` | `2.5` | m | Reject noisy nine-sample quadratic fits |
| `APOGEE_MAX_PREDICTION_JUMP_M` | `15.0` | m | Reject a new raw prediction that jumps too far from the last accepted raw prediction |
| `APOGEE_MAX_PREDICTION_SIGMA_M` | `8.0` | m | Reject unstable five-prediction history |
| `APOGEE_AGGREGATION_SIGMA_MULTIPLIER` | `2.0` | sigma | Use `mean + 2*sigma` over the latest five valid raw apogee predictions |
| `APOGEE_MAX_BARO_SAMPLE_GAP_MS` | `150` | ms | Reset apogee fit history after a stale barometer gap |
| `MIN_APOGEE_DETECT_ALT_M` | `30.0` | m AGL | Prevent low-altitude false deployment |
| `APOGEE_DROP_THRESHOLD_M` | `4.0` | m | Backup descent detector |
| `APOGEE_DESCENT_CONFIRM_SAMPLES` | `4` | samples | Consecutive backup descent samples |
| `BMP180_CONVERSION_TIMEOUT_MS` | `50` | ms | Matches the 50 ms barometer task period; BMP180 pressure/temperature conversions are polled non-blocking instead of using a blocking library path |
| `BMP180_OVERSAMPLING` | `0` | OSS | Team bring-up decision; OSS0 keeps pressure conversion short for scheduler-safe apogee sampling |
| `BMP180_TEMPERATURE_REFRESH_PRESSURE_SAMPLES` | `20` | pressure samples | BMP180 pressure compensation needs temperature-derived `B5`; temperature is refreshed periodically while pressure samples continue at the barometer task cadence |
| `BARO_MEDIAN_WINDOW_SAMPLES` | `3` | samples | Spike rejection in barometer task; implementation-local constant |
| `BARO_ALTITUDE_LPF_ALPHA` | `0.35` | ratio | First-order low-pass on median altitude; implementation-local constant, tune after replay |
| `BARO_STALE_FAULT_MS` | `300` | ms | Barometer health policy; stale last-valid sample threshold |
| `BARO_CONSECUTIVE_READ_FAIL_FAULT` | `5` | samples | Barometer health policy; repeated read/transport failures before fault |
| `BARO_BAD_VALUE_TOTAL_FAULT` | `10` | samples | Barometer health policy; total rejected bad values before fault |
| `BARO_BAD_VALUE_CONSECUTIVE_FAULT` | `5` | samples | Barometer health policy; consecutive rejected bad values before fault |
| `BARO_MIN_ALTITUDE_AGL_M` | `-200.0` | m AGL | Loose sanity bound; single out-of-range samples are rejected, not immediate fault |
| `BARO_MAX_ALTITUDE_AGL_M` | `5000.0` | m AGL | Loose sanity bound above expected NURA flight altitude |
| `BARO_STUCK_WINDOW_MS` | `5000` | ms | In-flight stuck detector window, only used after `COAST` |
| `BARO_STUCK_RANGE_M` | `0.2` | m | In-flight stuck detector window range |
| `TILT_MIN_ACCEL_NORM_G` | `0.2` | g | Reject tilt estimates when the low-g acceleration vector is too small to define direction |
| `TILT_MAX_ACCEL_NORM_G` | `3.0` | g | Reject tilt estimates during high-dynamic acceleration |
| `ATTITUDE_ACCEL_CORRECTION_MIN_NORM_G` | `0.7` | g | Enable attitude accel correction only near 1 g |
| `ATTITUDE_ACCEL_CORRECTION_MAX_NORM_G` | `1.3` | g | Disable attitude accel correction during high-dynamic acceleration |
| `ATTITUDE_ACCEL_CORRECTION_GAIN` | `0.8` | 1/s | Proportional correction gain from accel direction to quaternion attitude |
| `ATTITUDE_MAX_DELTA_MS` | `100` | ms | Reject attitude integration across stale IMU sample gaps |
| `BARO_FAULT_ATTITUDE_FALLBACK_MIN_FLIGHT_TIME_MS` | `8000` | ms | Do not allow attitude fallback before this time after launch |
| `BARO_FAULT_ATTITUDE_FALLBACK_TILT_DEG` | `70.0` | deg | Baro-fault late-apogee attitude trigger threshold |
| `BARO_FAULT_ATTITUDE_FALLBACK_CONFIRM_SAMPLES` | `5` | samples | Consecutive fresh low-g attitude samples required |
| `BARO_FAULT_ATTITUDE_FALLBACK_MAX_SAMPLE_AGE_MS` | `150` | ms | Reject stale low-g attitude samples |
| `PYRO_FIRE_DURATION_MS` | `50` | ms | Initial constant, must be verified by ground test |
| `DROGUE_BACKUP_DELAY_MS` | `2000` | ms | Team decision; delay between primary and backup drogue pyro |
| `MAIN_DEPLOY_ALTITUDE_M_AGL` | `200.0` | m AGL | Team-confirmed primary main-deployment threshold |
| `MAIN_DEPLOY_CONFIRM_SAMPLES` | `3` | samples | Existing noise rejection; three fresh filtered barometer samples at or below 200 m AGL |
| `LANDING_STABLE_WINDOW_SAMPLES` | `20` | samples | Team decision; landing detector window over fresh filtered barometer AGL samples |
| `LANDING_STABLE_ALTITUDE_RANGE_M` | `0.5` | m | Team decision; `max(window) - min(window)` must be below this, not adjacent-sample delta |
| `LANDING_MAX_BARO_SAMPLE_GAP_MS` | `150` | ms | Derived from 50 ms barometer period; reset landing window after stale samples |
| `APOGEE_TIMEOUT_MS` | `12000` | ms | Initial fallback, must be reviewed against simulation / flight data |
| `MAIN_BAROMETER_FAULT_TIMEOUT_MS` | `6000` | ms after `DROGUE` entry | Team-verified failsafe value; enabled only after `barometer.fault` is latched |
| `BENCH_FSM_AUTO_ARM_DELAY_MS` | `1000` | ms | Bench integration only; active only with `NURA_BENCH_FSM_AUTOFLOW` |
| `BENCH_FSM_AUTO_LAUNCH_DELAY_MS` | `1000` | ms | Bench integration only; replaces missing arming/launch stimulus |
| `BENCH_FSM_AUTO_BURNOUT_DELAY_MS` | `500` | ms | Bench integration only; lets the existing coast/apogee timers run |
| `BENCH_FSM_AUTO_GROUND_DELAY_MS` | `1000` | ms | Bench integration only; allows GROUND without a real landing barometer profile |

Notes:

- The 4-sample launch and burnout confirmations are intentionally sample-count
  based, not millisecond based.
- The launch and burnout confirmation source is low-g (`LSM6DSO32`) first.
  If low-g is stale or unavailable, the high-g IMU acceleration norm is used as a
  degraded fallback. A healthy low-g sample is never mixed with a high-g sample
  for the same detector step.
- Low-g IMU tilt fallback is also used after a barometer fault, but that is a
  separate apogee fallback path.

## State Table

| State | Entry action | Periodic action | Timeout | Fallback | Entry condition from previous state |
| --- | --- | --- | --- | --- | --- |
| `INIT` | Wait for board/bus settle, mount and preallocate the required microSD log, initialize program-flash logging, initialize sensors/calibration, build the barometer ground baseline, and force pyro outputs OFF. | Check initialization completion. | SD preparation failure is a hard init stop. | Panic hold with the four-beep storage pattern. | Boot starts here. |
| `SAFE` | Force pyro outputs OFF. Reset flight-local counters and detector state. | Hold SAFE while sensor and telemetry tasks continue globally; consume only a validated queued ARM request. | None. | None; rejected or unavailable uplink leaves the controller SAFE. | `INIT` completed, or active abort returned the FSM to SAFE. |
| `ARMED` | Reset launch detector consecutive count. Reset launch timestamp. Reset coast/apogee detector scratch state. | Compute selected acceleration norm and update launch confirmation count. | Optional arming timeout TODO. | `SAFE` if abort becomes active. | FSM consumed a matching authenticated ARM request while current state was SAFE and abort was inactive. |
| `LAUNCH` | Save `launch_time_ms`. Reset burnout confirmation count. TODO: log launch event later. | Continue selected acceleration norm monitoring and update burnout confirmation count. | Optional motor-burn timeout TODO. | `COAST` when motor-burn timeout policy is defined. | In `ARMED`, selected acceleration norm is `>= LAUNCH_ACCEL_THRESHOLD_G` for `LAUNCH_CONFIRM_SAMPLES` consecutive samples. |
| `COAST` | Save `coast_start_ms`. Reset apogee detector scratch state, including max altitude and descent counter. | Push fresh barometer AGL samples into the nine-sample predictor, update predicted-apogee and backup-descent confirmation counts. | `APOGEE_TIMEOUT_MS`. | `APOGEE`. | In `LAUNCH`, selected acceleration norm is `< BURNOUT_ACCEL_THRESHOLD_G` for `BURNOUT_CONFIRM_SAMPLES` consecutive samples. |
| `APOGEE` | Start drogue primary pyro pulse. Save pyro sequence start time. TODO: log drogue sequence start later. | End primary pulse after `PYRO_FIRE_DURATION_MS`; after `DROGUE_BACKUP_DELAY_MS`, fire backup pyro for `PYRO_FIRE_DURATION_MS`; keep all pyro timing non-blocking. | Pyro sequence timeout derived from backup delay plus pulse duration. | `DROGUE`. | Apogee detector asserts apogee, or `COAST` timeout fallback fires. |
| `DROGUE` | Latch drogue sequence complete. Reset main deploy detector scratch state. | With a healthy barometer, count fresh filtered AGL samples at or below 200 m. If the barometer fault latch is set, ignore altitude and evaluate only the six-second degraded timer. | No timer while barometer is healthy. `MAIN_BAROMETER_FAULT_TIMEOUT_MS` only while faulted. | `DEPLOY` after the fault-only timer. | Drogue primary-plus-backup pyro sequence is complete. This does not require proof that the parachute physically opened. |
| `DEPLOY` | Start main pyro pulse. Reset landing detector scratch state. TODO: support backup main pyro only if hardware/team policy requires it. TODO: log main deploy later. | End main pulse after `PYRO_FIRE_DURATION_MS`; after the pulse is complete, push fresh filtered barometer AGL samples into the landing detector. | None for first implementation. | None; timeout policy deferred to sensor fault / recovery policy. | In `DROGUE`, three fresh healthy-barometer samples are `<= MAIN_DEPLOY_ALTITUDE_M_AGL`; otherwise only a latched barometer fault may enable the six-second timer fallback. |
| `GROUND` | Force pyro outputs OFF. TODO: close/flush logs and enter recovery telemetry mode later. | TODO: recovery GPS/telemetry behavior. | None. | None. | Main deploy sequence is complete and the landing detector is stable. |
| `FAULT` | Force pyro outputs OFF. Set fault flag. TODO: log fault later. | Hold fault state. | None. | None. | Initialization failure or future critical fault policy. |

## Bench Integration Auto-Flow

Purpose: support radio/protocol integration tests on the real `main.cpp` app
when the rocket is not actually flying and no arming switch or pyro hardware is
connected yet.

Build gate:

```text
NURA_BENCH_FSM_AUTOFLOW == 1
```

Current PlatformIO usage: this flag is not exposed by the four standard
environments (`main`, `debug`, `main_no_lora`, and `debug_no_lora`). It remains a manual,
bench-only compile flag and must never be added to a flight build.

The additional `debug_lora_autoflow` environment is explicitly bench-only. It
inherits the SX1276 LoRa debug build, defines `NURA_BENCH_FSM_AUTOFLOW`, and
also defines `NURA_BENCH_FSM_STOP_AT_LAUNCH`. It therefore synthesizes
`SAFE -> ARMED -> LAUNCH` using the two delays above and holds in `LAUNCH`;
the automatic burnout/coast and recovery-output path is disabled in this
variant. Radio TX drive is limited to 2 dBm and radio-init failure is allowed
to keep wiring diagnostics observable.

Inputs and units:

- System time in ms.
- Current FSM state.
- Abort state.

No sensor value is treated as valid just because this mode is enabled. The mode
does not modify barometer, IMU, GPS, LoRa, or storage health.

Allowed states and actions:

```text
SAFE   -> ARMED  after BENCH_FSM_AUTO_ARM_DELAY_MS
ARMED  -> LAUNCH after BENCH_FSM_AUTO_LAUNCH_DELAY_MS
LAUNCH -> COAST  after BENCH_FSM_AUTO_BURNOUT_DELAY_MS
DEPLOY -> GROUND after BENCH_FSM_AUTO_GROUND_DELAY_MS
```

When `NURA_BENCH_FSM_STOP_AT_LAUNCH == 1`, the `LAUNCH -> COAST` leg is not
executed and the FSM remains in `LAUNCH`. This is the behavior of
`debug_lora_autoflow` and prevents this diagnostic build from advancing into
the recovery sequence.

The normal `COAST -> APOGEE`, `APOGEE -> DROGUE`, and `DROGUE -> DEPLOY`
paths still use the existing timer/sequence logic. This keeps the integration
test close to the real state order while removing only the currently missing
bench inputs.

Forbidden states:

- The mode must not run when `abortState.status.active == true`.
- The mode must not be enabled in a flight build.
- The mode must not energize pyro outputs directly. Current pyro behavior is
  still the existing FSM TODO/timing latch because real pyro HAL/pinmap is not
  defined yet.

Threshold sources:

- All four bench delays are team integration-test decisions. They are not
  flight thresholds and must not be used as launch, burnout, or landing logic.

Failure modes considered:

- Missing arming switch: bypassed only in bench build.
- No launch acceleration on the table: bypassed only in bench build.
- No barometer landing profile after main deploy: bypassed only in bench build.
- Active abort: auto-flow is inhibited.

Fallback behavior:

- If auto-flow is disabled, the normal FSM behavior is unchanged.
- If auto-flow reaches `COAST`, existing apogee and main timer fallbacks still
  drive the recovery sequence.

Verification plan:

- Host replay builds both normal FSM and `NURA_BENCH_FSM_AUTOFLOW` variants.
- The bench variant must reach `GROUND` without sensor events and without
  calling the panic handler.
- Hardware integration test, when the bench-only flag is deliberately enabled:
  connect the receiver and verify telemetry reports `SAFE -> ARMED -> LAUNCH
  -> COAST -> APOGEE -> DROGUE -> DEPLOY -> GROUND`.

## Init Failure Panic Feedback

Purpose:

- Keep init failure as a hard stop while making the board visibly and audibly
  alive during bench debugging.
- Leave USB processing time in the panic loop so firmware upload/recovery is
  less likely to look like a dead board.

Inputs and units:

- `Scheduler::lastInitFailureTaskName()`: name of the task whose `init()`
  returned `false`.
- Buzzer output: D2.
- Status LED output: D33. D34-D39 are treated as SDIO-reserved while built-in
  microSD logging is enabled.
- Pattern timing constants are in milliseconds.

Allowed state:

- Only before normal FSM operation starts, after a task init failure during
  `FlightControllerApp::setup()`.

Forbidden state:

- Normal flight states must not call this panic path for ordinary runtime
  degraded sensors. Runtime faults are handled by watchdog/fallback policy.

Behavior:

- `telemetry` init failure, currently LoRa bring-up failure: three short beeps,
  one second pause, repeat forever.
- Storage-related init failure: four short beeps, one second pause, repeat
  forever. In the current avionics build, `flight_log` storage is init-critical
  because the microSD logger is required.
- Any other init failure: two short beeps, one second pause, repeat forever.
- The status LED follows each beep.
- The loop uses `delay()` between tones and drains pending USB serial input so
  the Teensy USB stack has time to service host-side upload/recovery attempts.

Failure modes considered:

- Silent init stop mistaken for a dead board: mitigated by audible/LED pattern.
- Unknown init failure source: mapped to the two-beep generic pattern.
- LoRa failure during current SX1276 breakout bring-up debugging: mapped to a distinct
  three-beep pattern.

Verification plan:

- Build `main` and `debug` after the interface change.
- Force or observe a LoRa init failure on bench hardware and confirm the
  three-beep repeating pattern.
- Force a generic init failure in a bench build and confirm the two-beep
  repeating pattern.

## Detector Details

### Flight Acceleration Source And Norm

Launch and burnout detection use one selected acceleration source per fresh
sample. The primary source is low-g. The fallback source is high-g.

High-g is usable only when:

```text
highAccelOk == true
AND highG.connected == true
AND highG.hasNewData == true
AND highG.lastUpdatedMs is non-zero and fresh within ACCEL_FALLBACK_MAX_SAMPLE_AGE_MS
AND highG x/y/z values are finite
```

Low-g is usable only when:

```text
lowG.lastUpdatedMs is non-zero and fresh within ACCEL_FALLBACK_MAX_SAMPLE_AGE_MS
AND lowG accel x/y/z values are finite
```

Selection rule:

```text
if low-g is usable:
    use low-g
else if high-g is usable:
    use high-g
else:
    do not update launch/burnout confirmation this tick
```

The detector consumes only one new sample per source timestamp. If low-g is
healthy but has no new timestamp yet, the detector waits for low-g instead of
opportunistically mixing in high-g samples.

For high-g accelerometer values:

```text
accel_norm_g = sqrt(x_g^2 + y_g^2 + z_g^2)
```

For low-g values in m/s^2:

```text
accel_norm_g = sqrt(ax^2 + ay^2 + az^2) / 9.80665
```

### Launch Detection

Allowed only in `ARMED`.

```text
if accel_norm_g >= LAUNCH_ACCEL_THRESHOLD_G:
    launch_confirm_count += 1
else:
    launch_confirm_count = 0

if launch_confirm_count >= LAUNCH_CONFIRM_SAMPLES:
    transition to LAUNCH
```

### Burnout / Coast Detection

Allowed only in `LAUNCH`.

```text
if accel_norm_g < BURNOUT_ACCEL_THRESHOLD_G:
    burnout_confirm_count += 1
else:
    burnout_confirm_count = 0

if burnout_confirm_count >= BURNOUT_CONFIRM_SAMPLES:
    transition to COAST
```

No launch-to-coast inhibit is used in the first implementation. The team
decision is to use the four-sample confirmation directly.

### Apogee Detection

Allowed only in `COAST`.

First implementation uses these inputs:

- Filtered barometer AGL altitude.
- Max altitude seen since `COAST` entry.
- Coast elapsed time.

Explicit vertical-velocity estimation is a TODO item. The first implementation
fits against the filtered barometer AGL altitude value published by the
barometer task.

If the barometer fault flag is latched, the FSM stops using barometer primary
logic. In `COAST`, it first tries the attitude-based late-apogee fallback and
then falls through to the existing timer fallback. Barometer-fault main deploy
and landing still use timer / no-barometer behavior.

#### Low-g attitude / tilt estimate

`IMUTask` keeps a 6DOF quaternion attitude estimate. Gyro samples are integrated
every valid low-g IMU update. The first valid on-pad acceleration direction is
saved as the pad vertical reference; roll, pitch, yaw, and tilt are all relative
to that boot-time reference frame.

The estimator applies accelerometer correction only when the low-g acceleration
norm is close to 1 g:

```text
ATTITUDE_ACCEL_CORRECTION_MIN_NORM_G
  <= accel_norm_g <=
ATTITUDE_ACCEL_CORRECTION_MAX_NORM_G
```

Outside that window, the estimator uses gyro integration only. This prevents
motor thrust, coast dynamics, and deployment shock from being mistaken for
gravity direction.

The published FSM input is still a scalar tilt angle:

```text
tilt_angle_deg =
    angle_between(initial_pad_vertical, current_estimated_rocket_axis)
```

The roll/pitch/yaw fields are for logging and debugging. Yaw is expected to
drift without a trusted magnetometer correction, so the FSM does not use yaw or
pitch directly. It uses only `tiltAngleDeg`, and only as a degraded late-apogee
confirmation after the barometer has already been faulted.

#### Barometer altitude filtering

Barometer filtering runs in `BarometerTask`, before the FSM sees the sample.

Raw pressure is converted to pad-relative altitude:

```text
raw_altitude_m = 44330 * (1 - (pressure_pa / reference_pressure_pa)^0.19029495)
```

Then the altitude filter applies:

```text
median_altitude_m = median(latest 3 raw_altitude_m samples)
filtered_altitude_m += BARO_ALTITUDE_LPF_ALPHA *
                       (median_altitude_m - filtered_altitude_m)
```

On the first valid sample after initialization or read failure, the low-pass
state is initialized directly from the current median. This avoids a startup
ramp from zero altitude.

Telemetry field meaning:

| Field | Meaning | Used by flight logic |
| --- | --- | --- |
| `barometer.rawAltitudeM` | Direct pressure-derived AGL altitude before filtering | No |
| `barometer.altitudeM` | Median plus low-pass filtered AGL altitude | Yes |
| `barometer.fault` | Latched barometer fault flag | Yes |
| `barometer.faultFlags` | Fault reason bits: read fail, stale, bad value, stuck | Yes |

#### Barometer sample rejection and fault policy

Purpose: keep isolated bad barometer samples out of flight logic without
dropping into degraded mode too aggressively. The policy separates a rejected
sample from a latched sensor fault.

Inputs and units:

- BMP180 pressure in Pa.
- Pad-relative raw altitude in m AGL.
- Filtered altitude in m AGL.
- Sample timestamp in ms.

Allowed states:

- Sample rejection runs in the barometer task regardless of FSM state.
- Stuck detection runs only after `COAST`, currently in `COAST` and `DROGUE`.

Forbidden states:

- Stuck detection must not mark a fault on the pad.
- Stuck detection is not used in `DEPLOY`, because the landing detector also
  looks for a stable altitude window after main deployment.

Rejected sample policy:

```text
if pressure/altitude conversion is non-finite:
    reject this sample only

if raw_altitude_m < BARO_MIN_ALTITUDE_AGL_M:
    reject this sample only

if raw_altitude_m > BARO_MAX_ALTITUDE_AGL_M:
    reject this sample only
```

Rejected samples do not update `lastUpdatedMs`, `rawAltitudeM`, `altitudeM`, or
the altitude filter. They increment bad-value counters. A single `NaN`, `inf`,
or `-4000 m` style sample is not a fault by itself.

Fault policy:

```text
read failures >= BARO_CONSECUTIVE_READ_FAIL_FAULT
OR last valid sample age >= BARO_STALE_FAULT_MS
OR bad values >= BARO_BAD_VALUE_TOTAL_FAULT over the current boot
OR consecutive bad values >= BARO_BAD_VALUE_CONSECUTIVE_FAULT
OR in COAST/DROGUE:
       altitude range over BARO_STUCK_WINDOW_MS <= BARO_STUCK_RANGE_M
```

When any condition is met:

```text
barometer.fault = true
barometer.faultFlags |= reason
barometer.valid = false
```

The fault is intentionally latched for the current boot. Later valid-looking
samples may still be published for telemetry/debugging, but FSM primary
barometer logic ignores them while `barometer.fault == true`.

Apogee prediction and descent backup are ignored until:

```text
launch_elapsed_ms >= APOGEE_MIN_FLIGHT_TIME_MS
```

This suppresses early false apogee decisions during the first eight seconds
after launch.

#### Quadratic apogee prediction

The main apogee detector uses a sliding window of the latest nine filtered
barometric AGL altitude samples in `COAST`.

Fit:

```text
h(t) = a*t^2 + b*t + c
```

Use least-squares over all nine samples. Use relative seconds from the first
sample in the window; do not use raw `millis()` values in the fit.

Prediction:

```text
t_apogee = -b / (2*a)
h_apogee = c - (b*b) / (4*a)
```

The raw quadratic prediction is valid only when all conditions hold:

```text
sample_count == APOGEE_FIT_WINDOW_SAMPLES
a < -APOGEE_MIN_CURVATURE
a > -APOGEE_MAX_CURVATURE
fit_rmse_m <= APOGEE_MAX_FIT_RMSE_M
t_apogee > t_last
t_apogee - t_last <= APOGEE_MAX_PREDICT_AHEAD_S
h_apogee >= current_altitude
h_apogee - current_altitude <= APOGEE_MAX_ALT_MARGIN_M
current_altitude >= MIN_APOGEE_DETECT_ALT_M
launch_elapsed_ms >= APOGEE_MIN_FLIGHT_TIME_MS
abs(h_apogee - previous_raw_h_apogee) <= APOGEE_MAX_PREDICTION_JUMP_M
```

Then the deployment candidate uses the latest five accepted raw apogee
predictions:

```text
mean_h = mean(latest 5 accepted h_apogee values)
sigma_h = population_stddev(latest 5 accepted h_apogee values)
candidate_h = mean_h + 2 * sigma_h
```

This `plus2sigma5` candidate is deliberately conservative. It delays the
deployment trigger compared with the newest raw prediction and reduced early
deployment cases in the OpenRocket perturbation experiment.

The prediction history is valid only when:

```text
accepted_prediction_count >= APOGEE_PREDICTION_HISTORY_SAMPLES
sigma_h <= APOGEE_MAX_PREDICTION_SIGMA_M
```

Deployment trigger:

```text
valid_prediction_history
AND candidate_h - current_altitude >= 0
AND candidate_h - current_altitude <= APOGEE_DEPLOY_ALT_MARGIN_M
for APOGEE_CONFIRM_SAMPLES consecutive barometer samples
```

Quality checks intentionally prefer missing the prediction trigger over firing
too early. If the predictor is rejected, the FSM remains in `COAST` and can
still transition through the descent backup or coast timeout fallback.

#### Backup descent detection

```text
launch_elapsed_ms >= APOGEE_MIN_FLIGHT_TIME_MS
AND max_altitude - current_altitude >= APOGEE_DROP_THRESHOLD_M
for APOGEE_DESCENT_CONFIRM_SAMPLES consecutive barometer samples
```

Required fallback path:

```text
if coast_elapsed_ms >= APOGEE_TIMEOUT_MS:
    transition to APOGEE
```

This timer remains active when `barometer.fault == true`.

`APOGEE_TIMEOUT_MS` must not remain unreviewed for flight use and must be
greater than `APOGEE_MIN_FLIGHT_TIME_MS`.

#### Barometer-fault attitude fallback

Allowed only in `COAST` and only when `barometer.fault == true`.

Inputs:

- `imu.tiltValid`
- `imu.tiltAngleDeg`
- `imu.lastUpdatedMs`
- `flightState.launchMs`

Trigger:

```text
barometer.fault == true
AND now_ms - launch_ms >= BARO_FAULT_ATTITUDE_FALLBACK_MIN_FLIGHT_TIME_MS
AND low-g tilt sample is fresh
AND tilt_angle_deg >= BARO_FAULT_ATTITUDE_FALLBACK_TILT_DEG
for BARO_FAULT_ATTITUDE_FALLBACK_CONFIRM_SAMPLES consecutive samples
```

Then:

```text
transition to APOGEE
```

This is deliberately a late confirmation, not a prediction. It exists to avoid
waiting all the way to the timer fallback when the rocket has clearly tipped
over after apogee and the barometer is unavailable.

## Main Deployment Decision

Purpose: deploy the main parachute as the descending vehicle reaches 200 m AGL,
while retaining a bounded degraded path if the barometer is known to have
failed.

Inputs and units:

- `barometer.altitudeM`: filtered pad-relative altitude, m AGL.
- `barometer.lastUpdatedMs`: timestamp of the latest accepted sample, ms.
- `barometer.valid` and `barometer.referenceValid`: normal-path validity.
- `barometer.fault`: boot-latched barometer fault decision.
- `flightState.drogueMs`: `DROGUE` entry timestamp, ms.

The decision runs only in `DROGUE`. It is forbidden in `INIT`, `SAFE`,
`ARMED`, `LAUNCH`, `COAST`, `APOGEE`, `DEPLOY`, `GROUND`, and `FAULT`.

Normal path:

```text
barometer.fault == false
AND sample is valid, referenced, fresh, and not previously consumed
AND filtered_altitude_agl_m <= 200.0
for 3 consecutive fresh barometer samples
    -> transition to DEPLOY
```

There is no additional minimum time after `DROGUE` entry. This preserves the
team decision that reaching 200 m AGL is the primary deployment event. The
three-sample confirmation remains to reject one-off filtered-altitude noise.

Degraded path:

```text
barometer.fault == true
AND now_ms - drogue_entry_ms >= 6000
    -> transition to DEPLOY
```

The six-second value is a team-verified value supplied for this revision. The
timer starts at `DROGUE` entry. It is disabled for the entire time the
barometer fault latch is false, regardless of elapsed time or altitude. A
single rejected, stale-looking, `NaN`, or out-of-range sample does not enable
this fallback; the barometer task or in-flight stuck detector must first latch
`barometer.fault` under the documented fault policy. If that latch occurs after
six seconds have already elapsed, the fallback is accepted on the next FSM
tick.

Failure modes considered:

- Healthy barometer remains above 200 m: stay in `DROGUE`; no timer deployment.
- Isolated invalid sample: ignore it; do not count it and do not start fallback.
- Latched read, stale, bad-value, or stuck fault: stop using altitude and use
  only the six-second degraded timer.
- Altitude oscillates around 200 m: require three consecutive accepted samples.

Verification plan:

1. Host FSM test: healthy barometer above 200 m remains in `DROGUE` beyond six
   seconds.
2. Host FSM test: exactly three fresh samples at 200 m enter `DEPLOY`.
3. Host FSM test: a latched barometer fault cannot deploy before six seconds
   and does deploy at six seconds.
4. Next hardware session: replay a descending altitude profile, inject a
   barometer fault, and verify transition timestamps plus physical output with
   inert loads before any energetic test.

## Pyro Sequence

All pyro control must be non-blocking. Do not use `delay()` for firing pulses.

## State-Transition Buzzer Feedback

Purpose: make the active FSM transition audible during pad and bench operation.
The buzzer is diagnostic feedback only. It does not arm, inhibit, trigger, or
extend any pyro action, and a buzzer failure must not change the flight state.

Input and output:

- Input: the previous state, next state, and transition timestamp supplied by
  `FlightStateMachineTask::transitionTo()`.
- Output: D2 through `BuzzerHAL`, using non-blocking `tone()`/`noTone()` calls.
- Allowed operation: state transition feedback only.
- Forbidden operation: raw sensor input, LoRa packet parsing, pyro requests,
  arming authorization, and state-transition decisions.

Pattern assignment:

| Transition | Pattern | Duration |
| --- | --- | --- |
| `INIT -> SAFE` | Seven medium-pitch `2200 Hz` tones | `90 ms` ON / `80 ms` gap, seven times |
| `SAFE -> ARMED` | Continuous, full-amplitude `3000 Hz` alert tone | 5 s |
| All other state transitions | Five fast `2400 Hz` tones | `80 ms` ON / `80 ms` gap, five times |

Threshold source:

- The seven-beep init indication, 5 s flat arming alert, and five-beep
  transition convention are explicit team decisions.
- D2 is already driven with the maximum 3.3 V `tone()` amplitude. `3000 Hz` is
  the initial irritating alert frequency; the `90/80 ms` init cadence and
  `80/80 ms` transition cadence are initial audible defaults. They are not
  flight-control thresholds and may be retuned after a bench audibility test.

Failure modes and fallback:

- `BuzzerHAL::begin()` failure logs a warning and leaves the FSM muted; it does
  not cause `FAULT` or block deployment logic.
- The `INIT -> SAFE` seven-tone sequence queues the `SAFE -> ARMED` flat alert
  so the init indication finishes first. A later transition replaces the
  current diagnostic pattern immediately.
- Every pattern is serviced from the normal FSM tick without `delay()`, so it
  cannot intentionally stall sensor acquisition, timeout processing, or pyro
  pulse timing.

Verification plan:

- Host replay: `checkBuzzerStateTransitionPatterns()` verifies the seven-tone
  init sequence, queued flat alert, and five-tone transition pattern.
- Bench: with no e-matches connected, flash `debug_no_lora`, confirm D2 audio,
  and optionally scope the frequency/gaps while the board is shaken through
  `ARMED -> LAUNCH -> COAST`. Pyro remains dry-run unless the separate
  `NURA_ENABLE_PYRO_OUTPUTS` bench gate is deliberately enabled.

Physical channel mapping:

```text
Pyro 1 / Drogue -> BoardPinMap::DroguePyro
Pyro 2 / Main   -> BoardPinMap::MainPyro
```

The MOSFET HAL assumes active-high TC4452/MOSFET-driver inputs. It drives both
GPIO inputs listed for a channel together and treats the `sense` pin as input
only. Continuity interpretation is still deferred until the sense circuit is
characterized.

Allowed states and inputs:

- Drogue/Pyro 1 ON is allowed only on `APOGEE` entry and the retry point inside
  `APOGEE`.
- Main/Pyro 2 ON is allowed only on `DEPLOY` entry.
- `SAFE`, `GROUND`, and `FAULT` force all pyro outputs OFF.
- The only timing inputs used by this logic are `apogeeMs`, `deployMs`,
  `PYRO_FIRE_DURATION_MS`, and `DROGUE_BACKUP_DELAY_MS`, all in milliseconds.
- The pyro HAL does not read sensors, parse telemetry packets, or decide state
  transitions. It only executes requests from the FSM.

Failure modes considered:

- Boot/init failure: if physical pyro outputs are enabled and the HAL detects
  any overlap between D21 power sense and a pyro output, FSM init fails and the
  app enters the existing panic path. Current Drogue/Pyro 1 outputs are D28/D29.
  Main/Pyro 2 has been rerouted from the old D36/D37 pair to the D35/D38 output
  pair, with sense on D40. The exact gpio1/gpio2 order must be confirmed by
  continuity from Teensy pins to the MOSFET gate/driver nets before physical
  pyro outputs are enabled.
- Software reset or disarm: entering `SAFE`, `GROUND`, or `FAULT` calls
  `allOff()`.
- Continuity/sense failure: not acted on yet because the sense circuit has not
  been characterized. This remains a TODO before flight qualification.

Verification plan:

- Host replay: `checkPyroOutputSequence()` verifies Drogue ON/OFF/retry and
  Main ON/OFF call order without hardware.
- Bench GPIO test: with no e-matches attached, define `NURA_ENABLE_PYRO_OUTPUTS`
  and scope/LED-test D28/D29 and the confirmed D35/D38 Pyro 2 pair. Verify
  microSD logging still works during the same bench session before accepting
  the rerouted Pyro 2 pins.
- Hardware integration: verify continuity/sense readings before allowing arming
  gates to depend on them.

Build-time safety gate:

```text
default build:
    FSM calls the HAL, but MosfetPyroHAL is dry-run and does not drive GPIOs

NURA_ENABLE_PYRO_OUTPUTS:
    MosfetPyroHAL configures and drives the GPIO pins

NURA_ENABLE_PYRO_OUTPUTS without NURA_ALLOW_PYRO_POWER_SENSE_PIN_CONFLICT:
    init fails if a future pinmap maps battery voltage sense and a pyro output
    to the same pin
```

`NURA_ALLOW_PYRO_POWER_SENSE_PIN_CONFLICT` remains a bench-only escape hatch
for an intentionally modified pinmap. It is not needed for the current D21 and
D28/D29 assignment and must not be used in a flight build.

Drogue sequence in `APOGEE`:

```text
t = apogee_entry_ms

Drogue/Pyro 1 ON at t
Drogue/Pyro 1 OFF at t + PYRO_FIRE_DURATION_MS

Drogue/Pyro 1 retry ON at t + DROGUE_BACKUP_DELAY_MS
Drogue/Pyro 1 retry OFF at t + DROGUE_BACKUP_DELAY_MS + PYRO_FIRE_DURATION_MS

after retry OFF:
    transition to DROGUE
```

Main sequence in `DEPLOY`:

```text
t = deploy_entry_ms

main ON at t
main OFF at t + PYRO_FIRE_DURATION_MS

after main OFF:
    mark main sequence complete
    start accepting landing-detector barometer samples
```

Landing detector in `DEPLOY`:

```text
allowed only after mainSequenceComplete == true
input: filtered barometer altitude AGL, fresh sample timestamp

for each fresh barometer sample:
    if sample gap > LANDING_MAX_BARO_SAMPLE_GAP_MS:
        reset landing window
    push altitude into a 20-sample ring buffer

if the ring buffer is full
AND max(altitude_window) - min(altitude_window) <= LANDING_STABLE_ALTITUDE_RANGE_M:
    transition to GROUND

```

The detector intentionally uses the full 20-sample window range. It must not be
implemented as "20 adjacent differences below 0.5 m", because a slow parachute
descent can have adjacent 50 ms deltas below 0.5 m while still airborne.
A `DEPLOY -> GROUND` timeout fallback is intentionally deferred. A fixed timeout
can become an early-ground false positive if `DROGUE -> DEPLOY` entered by
timeout while the rocket was still high.

TODO:

- Confirm whether the main channel needs a backup channel and delay.
- Confirm actual e-match / igniter fire duration through ground test.
- Add continuity and battery checks in the later safety policy.

## Authenticated Uplink Arming

Production `SAFE -> ARMED` is command-gated. `TelemetryTask` verifies the frame,
CONTROL authentication, non-zero unexpired deadline, exact source/target state,
current SAFE state, inactive abort, and absence of a conflicting ARM/reset
request. It then records `FlightState.armRequested`; it never assigns the state.

On the next FSM tick, `consumeArmRequest()` rechecks SAFE and abort before calling
`transitionTo(State::ARMED)`. Execution is recorded only after `onEnter(ARMED)`
has completed. If abort becomes active in the acceptance-to-execution window,
the request is canceled, SAFE is retained, and telemetry returns a deferred
BAD_STATE rejection. ARM handling never energizes a pyro output.

The complete wire contract, failure handling, and verification plan are in
`documents/arm_uplink_state_transition_v1.md`.

## Uplink Forced Recovery Command

`FORCE_DEPLOY_RECOVERY` is handled as a request into the FSM, not as a direct
state write from telemetry parsing.

Allowed command path:

```text
TelemetryTask validates auth, freshness, format, and coarse state
TelemetryTask sets FlightState.forceRecoveryDeployRequested
FSM consumes the request on its next tick
FSM may transition LAUNCH/COAST -> APOGEE
TelemetryTask sends ACK_EXECUTED only after FSM records execution
```

Allowed states:

| Current state | Command result |
| --- | --- |
| `LAUNCH` | Request accepted; FSM may enter `APOGEE`. |
| `COAST` | Request accepted; FSM may enter `APOGEE`. |
| `APOGEE`, `DROGUE`, `DEPLOY` | Treated as already active / already done. |
| `INIT`, `SAFE`, `ARMED`, `GROUND`, `FAULT` | Rejected by state. |

This keeps packet reception, authentication, and ACK management in telemetry
while keeping the flight-state transition and recovery sequence under the FSM.

## TODO For Later Work

- Program-flash/SD logging policy and storage buffer sizing.
- Broader non-barometer degraded-mode transitions beyond high-g/low-g launch
  and burnout fallback.
- Barometer filter tuning.
- Tune landing detector thresholds with actual main-parachute descent logs.
- Decide whether a guarded `DEPLOY -> GROUND` timeout fallback is needed.
- Pyro continuity and battery voltage gating.
- Flight-log replay verification tests.

## Implementation Map

This table maps the documented logic to the current code so later reviews can
check implementation drift quickly.

| Logic / data | File | Code location / function | Notes |
| --- | --- | --- | --- |
| State enum and printable names | `src/core/states.h` | `enum class State`, `stateName()` | IDs match the telemetry state code table. |
| Mission thresholds and timeouts | `include/nura_constants.h` | `NuraConstants::Flight::*` | Flight constants are centralized here; protocol layout and board pins stay in their own source-of-truth files. |
| FSM task construction | `src/app/flight_controller_app.h` | `fsmTask_` member initialization | Passes `FlightState`, `AbortState`, `HighGImuState`, `ImuState`, and `TelemetryState` into the FSM. |
| FSM shared state | `src/state/flight_state.h` | `FlightState` | Stores current state and entry timestamps: launch, coast, apogee, drogue, deploy. |
| Low-g quaternion attitude estimate | `src/sensors/imu_task.cpp`, `src/state/imu_state.h` | `updateAttitudeEstimate()`, `ImuData::rollDeg/pitchDeg/yawDeg/tiltAngleDeg` | Integrates gyro, corrects with accel direction only near 1 g, and publishes roll/pitch/yaw plus the scalar FSM tilt. |
| Barometer telemetry fields | `src/state/telemetry_state.h` | `BarometerTelemetryData` | `rawAltitudeM` is unfiltered; `altitudeM` is filtered and used by FSM. |
| Barometer pressure-to-altitude conversion | `src/sensors/barometer_task.cpp` | `relativeAltitudeM()` | Uses pad reference pressure captured on first valid sample. |
| BMP180 conversion timing | `src/hal/bmp180_hal.cpp`, `include/nura_constants.h` | `BMP180HAL::begin()`, `BMP180HAL::poll()`, `BMP180` constants | Reads factory calibration coefficients, alternates temperature refresh with pressure conversions, and returns `PENDING` while conversion is in progress. Conversion timeout is counted as a read failure. |
| Barometer filtering | `src/sensors/barometer_task.cpp`, `src/sensors/barometer_task.h` | `BarometerTask::filterAltitude()` and filter member state | 3-sample median followed by EWMA alpha `0.35`. |
| Barometer sample publication | `src/sensors/barometer_task.cpp` | `BarometerTask::tick()` | Updates pressure, reference, raw altitude, filtered altitude, and sample timestamp. |
| Barometer sample rejection / fault latch | `src/sensors/barometer_task.cpp`, `src/state/telemetry_state.h` | `recordReadFailure()`, `recordBadValue()`, `markFault()`, `BarometerTelemetryData` | Rejects isolated bad samples; latches read-fail, stale, bad-value, and stuck fault flags after the configured thresholds. |
| Global task periods | `src/app/app_config.cpp`, `src/app/app_config.h` | `DefaultAppConfig::*TaskPeriodMs()` | Barometer period is 50 ms; magnetometer period is 100 ms; FSM period is 10 ms. |
| Watchdog recovery scheduling | `src/missions/watchdog_task.cpp`, `src/sensors/imu_task.cpp`, `src/sensors/high_g_imu_task.cpp`, `src/sensors/magnetometer_task.cpp`, `src/sensors/barometer_task.cpp` | `WatchdogTask::tick()`, sensor `recover()` / `initialize()` paths | Runtime recovery attempts are bounded to one immediate sensor `begin()` attempt per watchdog recovery interval. The recovery path avoids multi-attempt `delay()` loops that can stall FSM, telemetry, and sensor scheduling. |
| Nonblocking LoRa TX | `src/hal/sx1262_lora_hal.cpp`, `src/missions/telemetry_task.cpp` | `Sx1262LoRaHAL::send()`, `Sx1262LoRaHAL::service()`, `TelemetryTask::tick()` | TX starts with `startTransmit()` and completes from periodic service on DIO1 so LoRa airtime does not block FSM/sensor scheduling. ACKs are retained until TX starts; FAST/GPS samples may be skipped until the next period if TX cannot start. |
| INIT / abort handling / dispatch | `src/missions/fsm_task.cpp` | `FlightStateMachineTask::tick()` | `INIT -> SAFE`; active abort returns to `SAFE`; state-specific handlers are called here. |
| ARMED launch detection | `src/missions/fsm_task.cpp` | `tickArmed()`, `consumeFlightAccelSample()` | Selected acceleration norm `>= 2.0 g` for four fresh samples enters `LAUNCH`; low-g is primary, high-g is fallback. |
| LAUNCH burnout detection | `src/missions/fsm_task.cpp` | `tickLaunch()`, `consumeFlightAccelSample()` | Selected acceleration norm `< 1.0 g` for four fresh samples enters `COAST`; low-g is primary, high-g is fallback. |
| COAST apogee detection | `src/missions/fsm_task.cpp` | `tickCoast()`, `consumeBarometerSample()`, `pushApogeeSample()`, `apogeePredictionReady()` | Uses filtered barometer altitude, quality-checked nine-sample fit, `plus2sigma5` aggregation, descent backup, and timeout fallback. |
| Barometer-fault attitude fallback | `src/missions/fsm_task.cpp` | `baroFaultAttitudeFallbackReady()` | When barometer is faulted in `COAST`, requires launch+8 s, fresh valid tilt, tilt `>= 70 deg`, and five consecutive samples before `APOGEE`; timer fallback remains active. |
| In-flight barometer stuck detection | `src/missions/fsm_task.cpp` | `trackBarometerStuck()`, `markBarometerFault()` | Tracks 5 s altitude range only in `COAST`/`DROGUE`; latches `BARO_FAULT_STUCK` and leaves recovery to timer fallback. |
| Quadratic apogee fit | `src/missions/fsm_task.cpp` | `solveQuadratic()`, `solve3x3()` | Least-squares fit over nine samples using relative seconds from the oldest sample; also computes fit RMSE. |
| Apogee aggregation / quality checks | `src/missions/fsm_task.cpp` | `pushApogeePrediction()`, `plusTwoSigmaApogee()` | Rejects prediction jumps, unstable prediction history, high fit residual, stale barometer gaps, and uses `mean + 2*sigma` over five accepted raw predictions. |
| Forced recovery request | `src/missions/telemetry_task.cpp`, `src/state/flight_state.h` | `handleCommand()`, `forceDeployRequestAllowed()`, `FlightState::forceRecoveryDeployRequested` | Telemetry validates command/auth/state and records a request; it does not directly mutate the FSM state. |
| Forced recovery execution | `src/missions/fsm_task.cpp` | `consumeForceRecoveryDeployRequest()`, `forceRecoveryDeployAllowed()` | FSM consumes the request only in `LAUNCH` or `COAST`, transitions to `APOGEE`, and records execution for ACK. |
| Authenticated ARM validation | `src/missions/telemetry/arm_command_policy.h`, `src/missions/telemetry/telemetry_task.cpp` | `validateArmFlightCommand()`, `handleArmCommand()` | Requires non-zero unexpired deadline, exact SAFE-to-ARMED parameters, current SAFE, inactive abort, and no pending transition conflict. |
| ARM transition ownership | `src/missions/flight/fsm_task.cpp`, `src/state/flight_state.h` | `consumeArmRequest()`, ARM request/execution/rejection fields | Only the FSM enters ARMED; abort race cancels the request; telemetry sends EXECUTED only after state is ARMED. |
| Pyro HAL | `src/hal/pyro_output.h`, `src/hal/mosfet_pyro_hal.h`, `src/hal/mosfet_pyro_hal.cpp` | `IPyroOutput`, `MosfetPyroHAL` | MOSFET output abstraction; default dry-run, physical GPIO only with `NURA_ENABLE_PYRO_OUTPUTS`; blocks any future power-sense/pyro pin overlap. |
| Drogue pyro sequence state | `src/missions/fsm_task.cpp` | `onEnter(State::APOGEE)`, `tickApogee()` | Non-blocking Drogue/Pyro 1 pulse, then same-channel retry pulse after `DROGUE_BACKUP_DELAY_MS`; transitions to `DROGUE` after retry off. |
| Main deploy decision and sequence | `src/missions/flight/fsm_task.cpp` | `tickDrogue()`, `onEnter(State::DEPLOY)`, `tickDeploy()` | Healthy barometer: three fresh samples at `<= 200 m AGL`. Latched barometer fault only: six-second timer from `DROGUE` entry. Then runs the non-blocking Main/Pyro 2 pulse. |
| Landing / ground transition | `src/missions/fsm_task.cpp` | `tickDeploy()`, `consumeLandingSample()`, `landingStable()` | After main pulse completion, uses 20 fresh filtered barometer AGL samples and transitions to `GROUND` when window range is `<= 0.5 m`; timeout fallback is deferred. |
| Telemetry state code mapping | `src/missions/telemetry_task.cpp`, `protocol/include/nura_protocol_v1_lite.h` | `currentFlightStateCode()`, `FlightStateCode` | Downlink status encodes the new state IDs. |
| Protocol documentation state table | `documents/nura_lora_packet_protocol_v1.md` | `State encoding` section | Human-readable packet spec mirrors the code enum. |
| Mock flight data source | `src/hal/mock_flight_data_hal.cpp`, `src/missions/mock_telemetry_source_task.cpp` | `MockFlightDataHAL::read()`, `MockTelemetrySourceTask::tick()` | Generates deterministic nominal, low-apogee, noisy, gust, dropout, and pad-false-accel scenarios; publishes high-g IMU and filtered barometer data for mock builds. |
| Host FSM replay tests | `test/fsm_replay/flight_state_machine_replay.cpp`, `test/fsm_replay/run_fsm_replay_tests.py` | `runReplay()`, `checkFullFlight()`, `checkPyroOutputSequence()` | Compiles the real `fsm_task.cpp` with g++ and verifies launch, coast, apogee, drogue, deploy, ground, abort, forced recovery request, launch-confirmation behavior, and pyro output call order without a board. |
| Apogee perturbation experiment | `test/apogee_prediction/evaluate_apogee_prediction.py` | script entrypoint | Replays OpenRocket-derived altitude scenarios with environmental/sensor perturbations and compares apogee aggregation candidates. |

## Verification Commands

Board-free checks:

```bash
python3 test/fsm_replay/run_fsm_replay_tests.py
python3 test/apogee_prediction/evaluate_apogee_prediction.py
pio run -e main
pio run -e debug
pio run -e debug_no_lora
```

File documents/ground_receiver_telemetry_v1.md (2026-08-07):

# Ground Receiver Telemetry and Bench Command Gate V1

## Purpose

The ground-side Teensy receiver decodes authenticated NURA V2 Lite LoRa frames from the avionics radio and prints engineering-unit telemetry for GCS or serial-monitor use.

The default receiver firmware is receive-only. It must not transmit recovery/control commands when connected to real avionics hardware.

The ground SX1276 uses the flight link profile: 922.3 MHz, BW 125 kHz, SF7,
CR 4/5, preamble 8, sync word `0x12`, explicit header, and LoRa PHY CRC
enabled. These settings must match the avionics SX1276 exactly.

The current ground-module bench wiring uses `RXEN=D4` and `TXEN=D3`. The
receive-only `sx1276_ground` build drives RXEN high and TXEN low before radio
initialization. That polarity is an unverified bench assumption supplied with
the current wiring and must be checked against the module datasheet before any
uplink/transmit path drives the RF switch.

A separate `pair_test` PlatformIO environment enables automatic CONTROL/CMD transmission for the two-board bench protocol test only.

## Historical Avionics SX1262 Stabilization Notes

This section records the retired SX1262 bring-up phase. Current production
avionics uses the SX1276 path with `kFlightDownlinkOnly=false`; authenticated
uplink RX is required for `ARM_FLIGHT`. Do not use the historical downlink-only
setting below as the current flight configuration.

The avionics SX1262 SPI clock is held at 250 kHz for bring-up margin. RadioLib
owns the SX1262 version-string probe; the firmware no longer performs a manual
pre-probe before `radio.begin()` because extra SPI traffic before reset/wake can
make an already marginal MISO path harder to diagnose.

The current PCB label for D30 is ambiguous in bench results. Treating D30 as
RXE and driving it low made init fail with `raw_status=0x00`. Treating D30 as
reset allowed intermittent version-string reads, but TX completion still showed
intermittent `RADIOLIB_ERR_CHIP_NOT_FOUND`. The active firmware keeps D30 as the
SX1262 reset candidate for diagnosis, but this must be verified against the PCB
schematic/module datasheet before flight.

Current hardware observation: both the integrated firmware and the standalone
`avionics_radio_bench` sketch can report `raw_status=0x00`, meaning the MCU is
not receiving a valid SX1262 MISO/status byte. D30 high/low and MISO/MOSI swap
tests did not recover the raw status. Before claiming 10/10 init success, check
the LoRa module power, solder joints, MISO net continuity, MISO pull-down value,
SX1262 ground return, and whether the installed module exposes a separate reset
or RF-switch enable pin.

## Inputs and Units

FAST_TLM inputs from avionics:

| Field | Unit |
| --- | --- |
| `status_word` | bitfield defined in `nura_lora_packet_protocol_v1.md` |
| `boot_ms` | ms since avionics boot |
| `baro_dp_2pa` | pressure delta / 2 Pa |
| `low_accel_*_cg` | g * 100 |
| `gyro_*_dps10` | deg/s * 10 |
| `batt_mv` | mV, `0` if avionics marks the voltage sample invalid/unavailable |

GPS_TLM inputs from avionics:

| Field | Unit |
| --- | --- |
| `latitude_e7`, `longitude_e7` | degrees * 10,000,000 |
| `gps_alt_dm` | m * 10 |
| `speed_cms` | m/s * 100 |
| `course_cdeg` | degrees * 100 |
| `hdop_x10` | HDOP * 10 |
| `satellites` | count |
| `age_100ms` | 100 ms |

CONTROL/ACK inputs are decoded for operator visibility and pair-test validation.

Each LoRa PHY packet must contain exactly one complete NURA V2 Lite frame. The
receiver rejects oversized, truncated, concatenated, wrong-sync, wrong-version,
unknown-type, and bad-CRC frames before payload decoding.

## Allowed States

Receive-only mode is allowed for lab, integration, pad, and flight-rehearsal telemetry observation, subject to local radio legality and team operating procedures.

`pair_test` automatic command mode is allowed only when all of the following are true:

1. The setup is a bench protocol test.
2. The recovery output path is inhibited, disconnected, or otherwise intentionally made safe.
3. The firmware was explicitly built with `NURA_RECEIVER_AUTO_COMMAND_TEST` through `pio run -d receiver -e pair_test` or `receiver/tools/run_pair_test.py`.

## Forbidden States

`pair_test` automatic command mode is forbidden with flight-ready recovery hardware connected, with live energetic devices connected, or during any pad/flight operation.

The receive-only `teensy41` environment must remain the default build for real avionics telemetry checks.

## Thresholds and Sources

The command gate has no physical threshold. Its source is a team safety decision: automatic FORCE_DEPLOY_RECOVERY transmission is a bench-test feature and must be behind an explicit build flag.

The telemetry scaling thresholds and units come from `documents/nura_lora_packet_protocol_v1.md` and `protocol/include/nura_protocol_v1_lite.h`.
FAST `batt_mv` is decoded directly from the shared protocol header; the receiver
does not apply the ADC divider conversion because avionics already transmits
pack voltage in millivolts.

## Failure Modes Considered

- Operator uploads pair-test receiver firmware to real hardware by mistake.
- GCS emits FORCE_DEPLOY_RECOVERY after merely receiving telemetry.
- Serial output hides real sensor values, making hardware integration failures hard to identify.
- Pair-test automation breaks when the default receiver is made receive-only.
- A foreign or malformed LoRa packet is accepted across PHY packet boundaries.
- An oversized packet writes beyond the fixed receive buffer.
- A valid-format packet carries another vehicle ID, direction, key, or a
  modified authenticated field.

## Fallback Behavior

If `NURA_RECEIVER_AUTO_COMMAND_TEST` is not defined, `serviceCommandSender()` and pair-test completion printing return without transmitting commands.

Telemetry decode and CONTROL/ACK visibility remain active in both receiver environments.

The receiver accepts a frame only when its authenticated `vehicle_id`, direction,
payload, sequence, and tag match the configured secret. CRC remains a corruption
check and is not treated as identity. The checked-in fallback identity and key
are public bench values, so they do not establish sender authenticity against an
adversary. Flight use requires the same provisioned `nura_radio_secrets.h` on
the avionics and GCS build machines.

## Verification Plan

- Build receive-only receiver: `pio run -d receiver -e teensy41`.
- Build pair-test receiver: `pio run -d receiver -e pair_test`.
- Run script syntax check: `python3 -m py_compile receiver/tools/run_pair_test.py`.
- Hardware bench verification: upload real avionics firmware and receive-only receiver, then confirm FAST/GPS lines show changing IMU/barometer/GNSS fields and no `cmd tx` lines appear.
- Pair-test verification: run `python3 receiver/tools/run_pair_test.py --duration 20` with inhibited recovery outputs and confirm FAST/GPS/CONTROL pass criteria.

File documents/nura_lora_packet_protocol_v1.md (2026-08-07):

# NURA LoRa Packet Protocol V2 Authenticated Lite

Status: Draft for implementation  
Target vehicle: 2026 NURA avionics, sub-1 km class university rocket  
Target radios: SparkFun LoRa 1W Breakout SPX-18572 (E19-915M30S/SX1276)
on the flight and ground Teensy 4.1 test rigs, both using the same proprietary
LoRa PHY profile at 922.3 MHz
Target controller: Teensy 4.1  

This document defines the authenticated NURA V2 Lite application-layer packet format carried inside a LoRa PHY packet. The filename is retained to avoid breaking existing repository links. V2 intentionally removes nonessential packet classes so the radio spends less time transmitting and more time available for uplink commands.

This document is not a legal certification or RF compliance report. Frequency, output power, antenna gain, and LBT behavior must be verified against the final competition and Korean radio requirements before flight.

## 1. Design Decision

V1 Lite uses only three active payload classes:

```text
FAST_TLM   high-rate flight telemetry
GPS_TLM    slow recovery/navigation telemetry
CONTROL    uplink command and downlink command response
```

Removed from active V1 Lite:

```text
STATUS_TLM
EVENT_LOG
HEARTBEAT
separate CMD packet type
separate ACK packet type
```

The removed information is not forbidden forever. It is deferred until range tests prove there is enough airtime. In V1 Lite, every nonessential byte is treated as a command-window tax.

## 2. Operating Model

Telemetry is a lossy stream:

- FAST_TLM is never retransmitted.
- GPS_TLM is never retransmitted.
- Sequence gaps are recorded for link-quality estimation only.
- The newest valid sample wins.

Control is reliable enough for emergency use:

- GCS retransmits CONTROL/CMD until it receives CONTROL/ACK or the command expires.
- Avionics deduplicates commands by `command_seq`.
- A duplicate command must never re-execute an actuator action.
- ACK has higher priority than telemetry.
- Avionics keeps the radio in receive mode whenever it is not transmitting.

Safety rule:

```text
A CONTROL/CMD requests an action. It must not directly overwrite the flight state.
```

For recovery deployment, the command path should verify safety conditions and inject a recovery action/event into the flight or recovery controller. The parser itself must never energize a pyro channel.

## 3. RF Constraints and Rate Target

Recommended flight RF profile:

| Parameter | Flight default | Notes |
| --- | --- | --- |
| Frequency | 922.3 MHz | Must be identical on both SX1276 breakouts. |
| Bandwidth | 125 kHz | Preferred for link margin and regional channel compatibility. |
| Spreading factor | SF7 | Increase SF only after reducing traffic rate. |
| Coding rate | CR 4/5 | Higher CR increases airtime. |
| Preamble | 8 symbols | Default unless range tests show a need to change. |
| Sync word | `0x12` | Must be identical on both radios. |
| LoRa PHY CRC | Enabled | Application CRC is still required. |
| Header mode | Explicit | Easier interoperability and debugging. |
| EIRP | Must not exceed applicable limit | Include antenna gain and cable loss. |

`frequency`, bandwidth, spreading factor, coding rate, preamble, sync word,
header mode, and PHY CRC are an interoperability contract: both SX1276
breakouts must use the same values. Transmit power is local to each radio and
is not required to match.

The current SparkFun SX1276 1W breakout wiring is SPI1 MISO D1, MOSI D26,
SCK D27, NSS D9, RST D24, DIO0 D32, RXE D30, and TXE D31. RXE/TXE are the
module's external RF-switch enables and are active-high for this E19 module.
The module's RF power rail is 5 V; the Teensy control signals remain 3.3 V.
`main` and `debug` select this radio path, while
`main_no_lora` and `debug_no_lora` leave the radio disabled. Telemetry retries
radio initialization up to the configured limit (currently ten attempts) with
the configured retry delay before declaring LoRa unavailable.

The firmware's current `2 dBm` setting is the SX1276 core drive level; it is
not a promise of a measured 1 W EIRP. The external PA can draw roughly 630 mA
in transmit, so antenna connection, 5 V rail margin, thermal behavior, and
local EIRP/duty-cycle limits must be verified before enabling full-power tests.

The SX1276 HAL uses synchronous packet transmission. It selects TXE before
`endPacket()`, then returns to RXE and receive mode after the packet completes;
`TelemetryTask::tick()` keeps ACK frames ahead of FAST/GPS telemetry. If TX
cannot start, that telemetry sample is skipped until the next configured period.

At SF7/BW125/CR4/5/preamble 8/CRC on/explicit header, approximate airtime is:

| V2 Lite frame | Frame size | Approx. airtime |
| --- | ---: | ---: |
| FAST_TLM | 41 B | 87.3 ms |
| GPS_TLM | 37 B | 82.2 ms |
| CONTROL | 43 B | 87.3 ms |

Nominal schedule:

```text
FAST_TLM: 5 Hz
GPS_TLM: 1 Hz
CONTROL: on demand, telemetry may be skipped
```

Short burst schedule:

```text
FAST_TLM: 8 Hz
GPS_TLM: 1 Hz
CONTROL: on demand, telemetry may be skipped
```

Do not treat 10 Hz as the flight default. It may work in benign bench conditions, but it consumes too much receive-window margin for emergency uplink.

If the link degrades:

```text
1. Reduce FAST_TLM to 2-3 Hz.
2. Keep GPS_TLM at 1 Hz if recovery is still needed.
3. If needed, switch to SF8 at lower rates.
4. After landing, use low-rate GPS beacon and optionally SF9/SF10.
```

## 4. Application Frame

V2 Lite uses fixed-length payloads selected by message type. There is no `payload_len` field. This reduces overhead and parser complexity.

Frame overhead: 19 bytes.

| Offset | Type | Field | Description |
| ---: | --- | --- | --- |
| 0 | u8 | sync0 | Fixed 0xAA |
| 1 | u8 | sync1 | Fixed 0x55 |
| 2 | u8 | ver_type | Upper nibble = version, lower nibble = message type |
| 3 | u32 | vehicle_id | Expected vehicle identity |
| 7 | u16 | seq | Direction-local sequence number |
| 9 | bytes | payload | Fixed length by message type |
| 9 + payload_len | u8[8] | frame_auth_tag | SipHash-2-4 over direction, header, and payload |
| 17 + payload_len | u16 | crc16 | CRC over ver_type through authentication tag |

`ver_type`:

```text
bits 7..4: protocol version = 2
bits 3..0: message type
```

Message types:

| Type | Name | Direction | Payload bytes | Frame bytes |
| ---: | --- | --- | ---: | ---: |
| 0x1 | FAST_TLM | Avionics to GCS | 22 | 41 |
| 0x2 | GPS_TLM | Avionics to GCS | 18 | 37 |
| 0x3 | CONTROL | Bidirectional | 24 | 43 |
| 0x4..0xF | Reserved | - | - | - |

All multi-byte integers are little-endian.

Do not transmit raw C++ structs directly. Encode each field explicitly.

## 5. CRC

Recommended CRC:

```text
Name: CRC-16/CCITT-FALSE
Polynomial: 0x1021
Initial value: 0xFFFF
RefIn: false
RefOut: false
XorOut: 0x0000
Coverage: ver_type, vehicle_id, seq, payload, frame_auth_tag
Excluded: sync0, sync1, crc16 field
```

Frames with CRC failure must be dropped. A CRC-failed CONTROL/CMD must not be ACKed because command identity and payload integrity are not trustworthy.

### 5.1 Frame Authentication

Every frame carries an 8-byte SipHash-2-4 tag. The authenticated input is:

```text
direction_domain, ver_type, vehicle_id, seq, payload
```

`direction_domain` is `0x55` for uplink and `0x44` for downlink. It is not
transmitted; each endpoint supplies the expected direction while verifying.
This prevents a valid downlink frame from being reflected into the uplink path.

The receiver must compare `vehicle_id` with its configured vehicle, verify the
tag with the shared 128-bit key, and reject the frame before payload dispatch if
either check fails. The public fallback ID/key in the repository are for bench
tests only. Flight builds require a gitignored `include/nura_radio_secrets.h`.

## 6. Packet Validation

Each LoRa PHY packet must carry exactly one complete application frame:

```text
READ_BOUNDED_PACKET -> CHECK_LENGTH/TYPE -> CHECK_CRC -> CHECK_ID/MAC -> DISPATCH
```

Rules:

- Unknown version is a parse error.
- Unknown message type is rejected.
- Payload length is determined only by message type.
- Short, long, concatenated, and oversized PHY packets are rejected.
- The parser must not allocate dynamic memory.
- The radio FIFO must still be drained when the packet exceeds the application
  buffer, without writing past that buffer.

Maximum V2 Lite frame size:

```text
NURA_V2_MAX_FRAME_LEN = 43 bytes
```

## 7. Fixed-Point Encoding

Floating-point values are not transmitted in V2 Lite.

Signed invalid sentinel:

```text
i8 invalid  = -128
i16 invalid = -32768
i32 invalid = -2147483648
```

Unsigned invalid sentinel:

```text
u8 invalid  = 0xFF
u16 invalid = 0xFFFF
u32 invalid = 0xFFFFFFFF
```

Use saturating encode. If a value exceeds the valid range, clamp to the nearest valid non-sentinel value and clear the relevant status bit if the value is not trustworthy.

## 8. FAST_TLM Payload

FAST_TLM carries the minimum high-rate flight state.

Payload length: 22 bytes  
Frame length: 41 bytes

| Offset | Type | Field | Unit / encoding |
| ---: | --- | --- | --- |
| 0 | u16 | status_word | Sensor health and flight state bitfield |
| 2 | u32 | boot_ms | Milliseconds since avionics boot |
| 6 | i16 | baro_dp_2pa | `(pressure_pa - ground_pressure_pa) / 2` |
| 8 | i16 | low_accel_x_cg | Low-g acceleration, `g * 100` |
| 10 | i16 | low_accel_y_cg | Low-g acceleration, `g * 100` |
| 12 | i16 | low_accel_z_cg | Low-g acceleration, `g * 100` |
| 14 | i16 | gyro_x_dps10 | Gyro, `deg/s * 10` |
| 16 | i16 | gyro_y_dps10 | Gyro, `deg/s * 10` |
| 18 | i16 | gyro_z_dps10 | Gyro, `deg/s * 10` |
| 20 | u16 | batt_mv | Battery voltage in mV. `0` means unavailable or invalid. |

`batt_mv` is intentionally kept as a raw unsigned millivolt value instead of a
floating-point voltage. The avionics firmware currently derives it from the
battery divider with a measured division ratio of 5.545:

```text
sense_mv   = raw_adc / 1023 * 3300
batt_mv    = sense_mv * 5545 / 1000
```

This preserves 1 mV packet resolution while keeping the FAST payload at 22
bytes. The field is not a flight-safety decision input in V1 Lite; if the ADC
reading is stale or outside the sanity range, avionics sends `0`.

Implementation notes for V1 Lite:

- Purpose: ground visibility of the avionics battery pack voltage.
- Source: D22 analog voltage divider. The final Pyro 1 outputs are D28/D29,
  so the voltage input does not share a pyro output pin.
- Calibration source: team board measurement/calculation: divider ratio 5.545;
  12.6 V maps to 2.2723 V (about raw ADC 704) and 11.1 V maps to 2.0018 V
  (about raw ADC 620) on a 10-bit, 3.3 V ADC.
- Sanity range: firmware accepts 6.0 V to 14.0 V as a valid electrical reading.
  The 11.1 V to 12.6 V values above are the expected 3S operating range, not a
  state-machine or pyro threshold.
- Allowed states: all states, because this is telemetry-only.
- Forbidden use: do not use `batt_mv` as a pyro, arming, or state-transition
  gate until the power hardware and threshold policy are separately validated.
- Fallback behavior: invalid, stale, or unavailable samples downlink as `0`.
- Verification: bench-feed the divider with known voltages, confirm receiver
  `batt_mv` printout and local log `battery_mv` match the expected pack voltage.
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

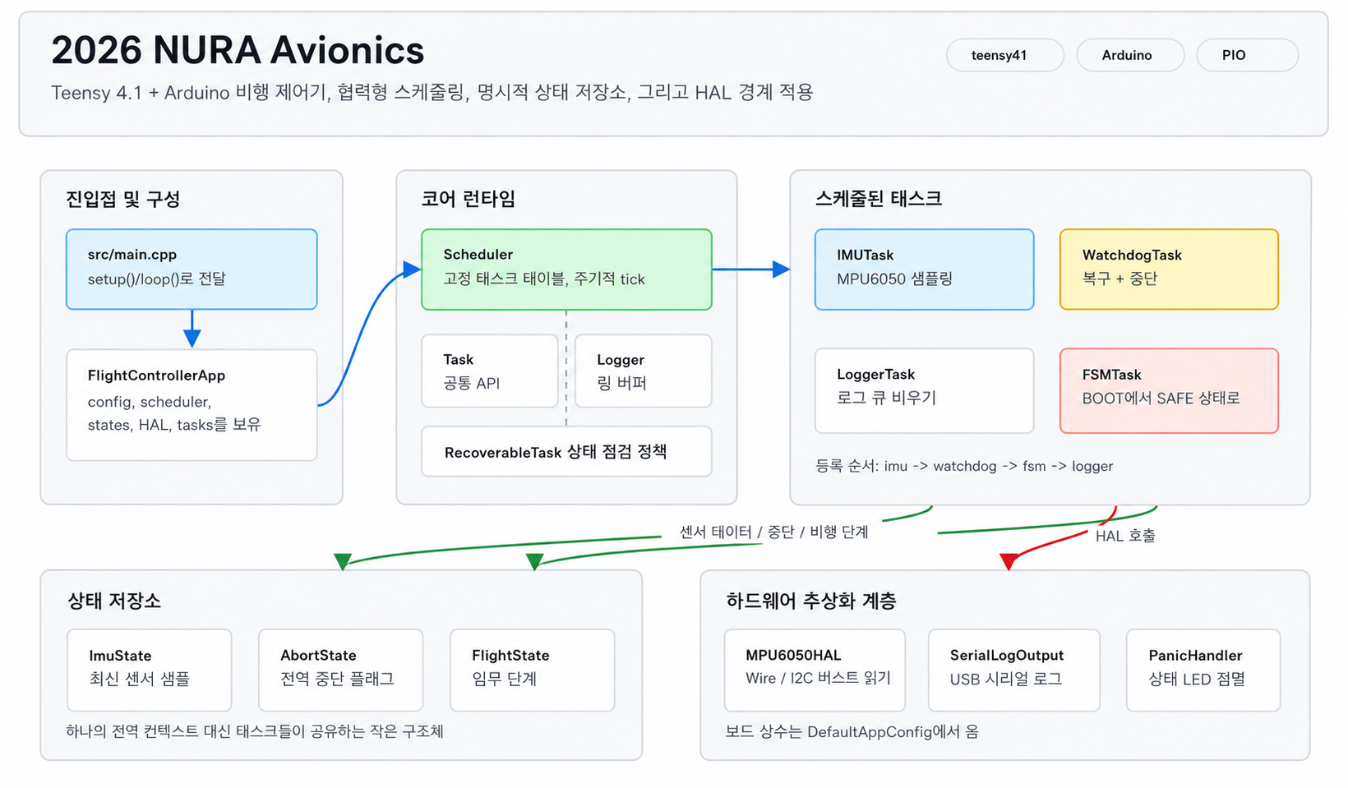
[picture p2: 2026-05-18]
documents/project-architecture_KR.png

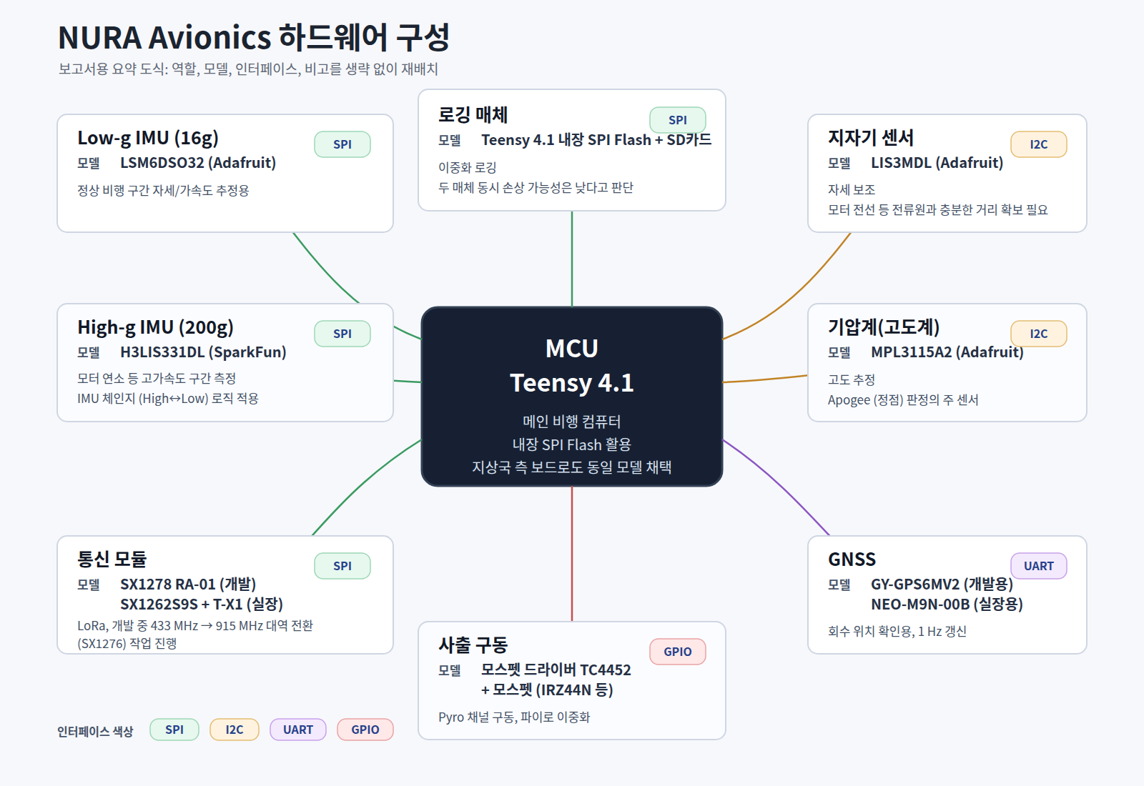
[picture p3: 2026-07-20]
documents/nura_avionics_hardware_figure.png

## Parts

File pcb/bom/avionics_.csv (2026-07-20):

Id | 지정자 | 풋프린트 | 수량 | 지정 | 공급자와 참조
1 | BZ1 | Buzzer_12x9.5RM7.6 | 1 | Buzzer
2 | C1 | C_0805_2012Metric | 1 | 1u
3 | C4, C6, C7, C9, C11, C15, C16, C18, C21 | C_0805_2012Metric | 9 | 100n
4 | C5, C20 | C_0805_2012Metric | 2 | 100p
5 | C8, C17 | C_0805_2012Metric | 2 | 10u
6 | C10, C12, C13, C14, C19 | C_0805_2012Metric | 5 | 22u
7 | D1, D2 | LED_D1.8mm_W3.3mm_H2.4mm | 2 | LED
8 | F1 | Fuse_2410_6127Metric | 1 | 5A
9 | J1 | U.FL_Hirose_U.FL-R-SMT-1_Vertical | 1 | U.FL-R-SMT-1(10)
10 | J3 | PinHeader_2x05_P2.54mm_Vertical | 1 | Conn_LoRA
11 | JP1 | SolderJumper-2_P1.3mm_Open_Pad1.0x1.5mm | 1 | GPS_RST
12 | J_POWER1 | AMASS_XT60-F_1x02_P7.20mm_Vertical | 1 | XT60
13 | J_PYRO1, J_PYRO2 | TerminalBlock_MaiXu_MX126-5.0-02P_1x02_P5.00mm | 2 | IGNITER_5R6
14 | L1 | L_Changjiang_FXL1050 | 1 | 10uH
15 | Q1, Q2, Q3, Q4 | TO-252-2 | 4 | IRLR8726
16 | R3, R15 | R_0805_2012Metric | 2 | 330k
17 | R4, R16 | R_0805_2012Metric | 2 | 68k
18 | R5 | R_0805_2012Metric | 1 | 180k
19 | R6, R9, R17, R19 | R_0805_2012Metric | 4 | 100
20 | R7, R10, R13, R18, R20 | R_0805_2012Metric | 5 | 100k
21 | R8 | R_0805_2012Metric | 1 | 30k
22 | R11 | R_0805_2012Metric | 1 | 150k
23 | R12 | R_0805_2012Metric | 1 | 1k
24 | R14 | R_0805_2012Metric | 1 | 33k
25 | R21, R22, R23, R24, R27, R28, R29 | R_0805_2012Metric | 7 | 4.7k
26 | R25, R26 | R_0805_2012Metric | 2 | 220
27 | SW1 | TerminalBlock_MaiXu_MX126-5.0-02P_1x02_P5.00mm | 1 | ARM
28 | U1 | LSM6DSOX | 1 | Adafruit_LSM6DSO32
29 | U2 | Sparkfun_H3LIS331DL | 1 | Sparkfun_H3LIS331DL
30 | U3 | Adafruit_MPC3315A2 | 1 | Adafruit_MPC3315A2
31 | U4 | Teensy41 | 1 | Teensy4.1
32 | U5 | Adafruit_LIS3MDL | 1 | LIS3MDL
33 | U6 | GPSM-SMD_24P-L16.0-W12.2-P1.10-BL | 1 | NEO-M9N-00B
34 | U8 | SOT-223-3_TabPin2 | 1 | MCP1825S-5002
35 | U9 | TSOT-23-6 | 1 | AP63200WU-7
36 | U10 | SOT-23-5 | 1 | AP2210K-3.3

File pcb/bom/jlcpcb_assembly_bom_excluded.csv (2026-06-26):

Reference | Value | Footprint | LCSC Part | Reason
BZ1 | Buzzer | Buzzer_Beeper:Buzzer_12x9.5RM7.6 |  | not SMD/THT; no LCSC/JLCPCB part
D1 | LED | LED_THT:LED_D1.8mm_W3.3mm_H2.4mm |  | not SMD/THT; no LCSC/JLCPCB part
D2 | LED | LED_THT:LED_D1.8mm_W3.3mm_H2.4mm |  | not SMD/THT; no LCSC/JLCPCB part
JP1 | GPS_RST | Jumper:SolderJumper-2_P1.3mm_Open_Pad1.0x1.5mm |  | not SMD/THT; no LCSC/JLCPCB part
JP2 | LORA_RST | Jumper:SolderJumper-2_P1.3mm_Open_Pad1.0x1.5mm |  | not SMD/THT; no LCSC/JLCPCB part
J_POWER1 | XT60 | Connector_AMASS:AMASS_XT60-F_1x02_P7.20mm_Vertical |  | not SMD/THT; no LCSC/JLCPCB part
J_PYRO1 | IGNITER_5R6 | TerminalBlock:TerminalBlock_MaiXu_MX126-5.0-02P_1x02_P5.00mm |  | not SMD/THT; no LCSC/JLCPCB part
J_PYRO2 | IGNITER_5R6 | TerminalBlock:TerminalBlock_MaiXu_MX126-5.0-02P_1x02_P5.00mm |  | not SMD/THT; no LCSC/JLCPCB part
SW1 | ARM | TerminalBlock:TerminalBlock_MaiXu_MX126-5.0-02P_1x02_P5.00mm |  | not SMD/THT; no LCSC/JLCPCB part
U1 | Adafruit_LSM6DSO32 | avionics:LSM6DSOX |  | not SMD/THT; no LCSC/JLCPCB part
U2 | Sparkfun_H3LIS331DL | avionics:Sparkfun_H3LIS331DL |  | not SMD/THT; no LCSC/JLCPCB part
U3 | Adafruit_MPC3315A2 | avionics:Adafruit_MPC3315A2 |  | not SMD/THT; no LCSC/JLCPCB part
U4 | Teensy4.1 | avionics:Teensy41 |  | not SMD/THT; no LCSC/JLCPCB part
U5 | LIS3MDL | avionics:Adafruit_LIS3MDL |  | not SMD/THT; no LCSC/JLCPCB part
U8 | MCP1825S-5002 | Package_TO_SOT_SMD:SOT-223-3_TabPin2 |  | no LCSC/JLCPCB part

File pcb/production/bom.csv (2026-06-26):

Designator | Footprint | Quantity | Value | LCSC Part #
BZ1 | Buzzer_12x9.5RM7.6 | 1 | Buzzer
C1, C2 | 0805 | 2 | 1u | C28323
C10, C12, C13, C14, C19 | 0805 | 5 | 22u | C45783
C11, C15, C16, C18, C21, C4, C6, C7, C9 | 0805 | 9 | 100n | C49678
C17, C8 | 0805 | 2 | 10u | C15850
C20, C5 | 0805 | 2 | 100p | C1790
C3 | 0805 | 1 | 1n | C1791
D1, D2 | LED_D1.8mm_W3.3mm_H2.4mm | 2 | LED
F1 | 2410 | 1 | 5A | C178993
J1, J2 | U.FL_Hirose_U.FL-R-SMT-1_Vertical | 2 | U.FL-R-SMT-1(10) | C88373
JP1 | SolderJumper-2_P1.3mm_Open_Pad1.0x1.5mm | 1 | GPS_RST
JP2 | SolderJumper-2_P1.3mm_Open_Pad1.0x1.5mm | 1 | LORA_RST
J_POWER1 | AMASS_XT60-F_1x02_P7.20mm_Vertical | 1 | XT60
J_PYRO1, J_PYRO2 | TerminalBlock_MaiXu_MX126-5.0-02P_1x02_P5.00mm | 2 | IGNITER_5R6
L1 | L_Changjiang_FXL1050 | 1 | 10uH | C5359264
Q1, Q2, Q3, Q4 | TO-252-2 | 4 | IRLR8726 | C5350860
R1, R2 | 0805 | 2 | 10k | C17414
R10, R13, R18, R20, R7 | 0805 | 5 | 100k | C149504
R11 | 0805 | 1 | 150k | C17470
R12 | 0805 | 1 | 1k | C17513
R14 | 0805 | 1 | 33k | C17633
R15, R3 | 0805 | 2 | 330k | C17629
R16, R4 | 0805 | 2 | 68k | C17801
R17, R19, R6, R9 | 0805 | 4 | 100 | C17408
R21, R22, R23, R24 | 0805 | 4 | 4.7k | C17673
R25, R26 | 0805 | 2 | 220 | C17557
R5 | 0805 | 1 | 180k | C17501
R8 | 0805 | 1 | 30k | C17621
SW1 | TerminalBlock_MaiXu_MX126-5.0-02P_1x02_P5.00mm | 1 | ARM
U1 | LSM6DSOX | 1 | Adafruit_LSM6DSO32
U10 | SOT-23-5 | 1 | AP2210K-3.3 | C176959
U2 | Sparkfun_H3LIS331DL | 1 | Sparkfun_H3LIS331DL
U3 | Adafruit_MPC3315A2 | 1 | Adafruit_MPC3315A2
U4 | Teensy41 | 1 | Teensy4.1
U5 | Adafruit_LIS3MDL | 1 | LIS3MDL
U6 | GPSM-SMD_24P-L16.0-W12.2-P1.10-BL | 1 | NEO-M9N-00B | C5119087
U7 | WIRELM-SMD_SX1278S165SY-T-X1 | 1 | SX1262S9S+T-X1 | C718839
U8 | SOT-223-3_TabPin2 | 1 | MCP1825S-5002
U9 | TSOT-23-6 | 1 | AP63200WU-7 | C2071868

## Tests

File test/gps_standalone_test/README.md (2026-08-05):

# GPS Standalone Test

Independent Teensy 4.1 test for the avionics u-blox M6 UART and NMEA output.
It does not initialize flight state, pyro, storage, sensors, or LoRa.

```bash
pio run -d test/gps_standalone_test -e gps_standalone -t upload
pio device monitor -p /dev/ttyACM0 -b 115200
```

`RESULT GPS_NMEA_LINK PASS` proves that UART data and valid NMEA checksums are
working. `RESULT GPS_FIX PASS` additionally requires a usable satellite fix and
normally needs an outdoor sky view.

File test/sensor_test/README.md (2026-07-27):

# Sensor Defect Test Sketches

Each `.ino` file in this folder is a standalone bring-up sketch for one sensor/module.
The active bring-up sketches target Teensy 4.1.

Shared SPI wiring for H3LIS331DL, the low-g IMU, and LoRa:

- MOSI: 11
- MISO: 12
- SCK: 13
- Low-g IMU CS: 10
- H3LIS331DL CS: 0
- LoRa NSS/SS: 9
- LoRa RST: 24
- LoRa RXE: 30
- LoRa TXE: 31
- LoRa DIO0: 32

I2C wiring on the current PCB:

- MPL3115A2: Wire / SDA0 18 / SCL0 19
- LIS3MDL: Wire1 / SDA1 17 / SCL1 16

Other current PCB pins:

- GPS TX -> 15 / RX3, GPS RX -> 14 / TX3
- Buzzer: 2
- LED1: 34
- LED2: 33
- Pyro 1 / Drogue: gpio1 28, gpio2 29, sense 25
- Pyro 2 / Main: gpio1 38, gpio2 35, sense 41
- Battery voltage sense: 22

Usage:

1. Open one `.ino` file at a time.
2. Edit sensor pins in `include/board_pinmap.h` if the wiring changes.
3. Edit non-pin test settings in the `PIN MAP / USER CONFIG` block if needed.
4. Upload to the target board named in the sketch.
5. Open Serial Monitor at `115200`.
6. Check `PASS`, `WARN`, and `FAIL` lines.

These sketches are for breakout bring-up and defect screening before PCB integration.
They do not replace full calibration, environmental testing, or flight qualification.

Required Arduino libraries:

- Adafruit LSM6DS
- Adafruit LIS3MDL
- Adafruit LIS331
- Adafruit MPL3115A2 Library
- TinyGPSPlus
- LoRa by Sandeep Mistry

Files:

- `lsm6dsox_low_g_imu_test.ino`
- `lsm6dso32_low_g_imu_test.ino`
- `h3lis331dl_high_g_accel_test.ino`
- `lis3mdl_mag_test.ino`
- `mpl3115a2_baro_test.ino`
- `ublox_m6_gnss_test.ino`
- `sx127x_lora_test.ino` - legacy RA-01/SX1278 433 MHz sketch; use
  `test/sx1276_breakout/` for the current SparkFun SPX-18572 1 W wiring and
  922.3 MHz bench profile.

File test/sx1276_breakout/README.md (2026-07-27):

# SparkFun SPX-18572 / E19-915M30S SX1276 1W standalone test

This is a bench-only Teensy 4.1 test for the SparkFun LoRa 1W Breakout
(SPX-18572, E19-915M30S) with its external RX/TX RF switch.

The supplied wiring is:

| SX1276 breakout | Teensy 4.1 |
| --- | ---: |
| MISO | 1 (SPI1) |
| MOSI | 26 (SPI1) |
| SCK | 27 (SPI1) |
| NSS | 9 |
| RST | 24 |
| RXE | 30 |
| TXE | 31 |
| DIO0 | 32 |
| VCC | 5 V module rail (4.75-5.5 V recommended) |
| GND | GND |

`RXE` and `TXE` are RF-path enable signals, not UART receive/transmit pins. The
test assumes both are active high: receive is `RXE=1, TXE=0`, transmit is
`RXE=0, TXE=1`, and standby is `RXE=0, TXE=0`. Confirm that polarity against
the exact breakout schematic before transmitting.

The SparkFun/E19 module uses 5 V on its power input while its SPI/GPIO control
signals are 3.3 V logic. Keep the antenna connected and current-limit the
module rail during bring-up. The default RF profile is the repository
ground-radio profile: 922.3 MHz,
BW 125 kHz, SF7, CR 4/5, sync word `0x12`, CRC enabled, explicit header, and
2 dBm bench transmit power. Use a breakout and antenna matched to that band.

Build and upload from the repository root:

```sh
pio run -d test/sx1276_breakout
pio run -d test/sx1276_breakout -t upload
pio device monitor -d test/sx1276_breakout -b 115200
```

The sketch starts in continuous receive mode. Serial commands are:

- `t`: transmit one test packet and return to receive mode.
- `r`: enter receive mode.
- `q`: enter standby and disable both RF paths.
- `s`: print counters, state, and the RXE/TXE pin levels.
- `h`: print command help.

One radio alone can prove SPI communication, reset, DIO0 interrupt handling,
and RF-switch GPIO behavior. A real RF pass/fail test needs a second radio with
the same frequency, bandwidth, spreading factor, coding rate, sync word,
preamble, CRC, and header mode. Connect the correct antenna before issuing `t`.

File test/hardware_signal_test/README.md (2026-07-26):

# Hardware Signal Test

Standalone raw-bus diagnostic for the assembled avionics PCB.

- H3LIS331DL and LSM6DSO32: SPI0 identity stress and register write/readback
- MPL3115A2: I2C0 identity stress, idle levels, and register write/readback
- E19-915M30S/SX1276: SPI1 identity matrix and RF-switch GPIO test, with no RF transmission
- u-blox GNSS: UART receive validation and read-only UBX MON-VER poll

Pyro pins remain inputs with pulldowns. This project does not link the flight
application, sensor HALs, mission logic, storage, or telemetry tasks.

Send `r` over USB serial to repeat the complete test.

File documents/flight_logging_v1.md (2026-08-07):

# NURA Flight Logging V1

Status: Implemented; hardware latency qualification pending

Target controller: Teensy 4.1

Persistent storage:

- Primary: Teensy 4.1 U3 W25Q128 QSPI NOR flash, 16 MiB raw journal
- Required mirror: built-in SDIO microSD, one 16 MiB preallocated file per boot

## 1. Purpose and safety boundary

The flight logger records the sensor values seen by the flight computer and the
evidence used by the recovery state machine. Logging must never delay sensor
sampling, FSM execution, telemetry, or pyro sequencing for a flash erase or SD
card busy interval.

The scheduler is cooperative. Therefore a storage function which waits for a
medium to finish is equivalent to stopping every task. The runtime storage
contract is consequently:

1. `append()` only copies an already encoded frame into fixed RAM.
2. `service()` performs at most one bounded controller transaction or starts one
   medium operation and returns.
   `FlightLogTask` invokes it at most once per scheduler tick, including while
   completing the GROUND flush.
3. QSPI page-program and erase completion are checked with one status-register
   read on a later scheduler tick. There is no WIP busy-wait in runtime code.
4. SD data is submitted only when `FsFile::isBusy()` is false. One call submits
   one 512-byte SDIO FIFO block.
5. No runtime path calls LittleFS, FAT allocation, FAT sync, file truncate, or
   file close.

Blocking operations are permitted only before `Scheduler::init()`:

- SD mount, directory creation, file creation and preallocation
- QSPI JEDEC identification and journal scan
- bounded completion wait for a NOR operation left active across an MCU-only reset
- first QSPI sector erase and journal-header program when no journal exists

Those operations can delay boot, but cannot delay a running flight task.

microSD is a mandatory boot dependency. Failure to mount the card, create the
log directory, create the session file, or preallocate it causes an init panic
before sensor-task initialization. A healthy program-flash journal does not
override a failed microSD check.

## 2. Logical record stream

`FlightLogTask` creates one logical byte stream. The stream contains complete
application frames and is identical before the SD and QSPI physical wrappers
are applied.

```text
FrameHeader (14 bytes)
    magic             uint16  0x4E4C, "NL"
    version           uint8   1
    type              uint8
    payload_length    uint16
    sequence          uint32
    timestamp_ms      uint32

payload               payload_length bytes
crc16_ccitt           uint16, header + payload
```

Chunk and sector boundaries are not application-frame boundaries. A frame can
cross a QSPI page or SD block. Recovery tooling first reconstructs the logical
stream and then validates each application frame CRC.

## 3. Production rate and RAM budget

Current encoded sizes are:

| Record | Encoded size | Rate | Byte rate |
| --- | ---: | ---: | ---: |
| FAST | 82 B | 50 Hz | 4,100 B/s |
| SLOW | 76 B | 10 Hz | 760 B/s |
| EVENT/DECISION | variable | event driven | normally small |

Nominal periodic production is approximately 4.86 kB/s.

| Buffer | Size | Ownership | Purpose |
| --- | ---: | --- | --- |
| Encoded frame FIFO | 16 KiB | `FlightLogTask` | Absorbs aggregate storage backpressure; drops oldest complete frames on overflow. |
| QSPI byte queue | 8 KiB | QSPI backend | Two 4 KiB-equivalent staging banks; drains as 240-byte journal payloads. |
| SD byte queue | 8 KiB | SD backend | Two 4 KiB-equivalent staging banks; drains as 488-byte journal payloads. |

The storage queues provide about 1.6 seconds of local buffering at the nominal
rate. The upstream 16 KiB FIFO adds approximately 3.3 seconds. Records are moved
from the upstream FIFO only when every currently active backend has room, so a
short busy period does not cause the two copies to diverge.

## 4. QSPI raw journal

LittleFS is not used by the flight logger. The previous implementation called
`LittleFS_QSPIFlash::write()` and `usedSize()` from the cooperative task. The
Teensy LittleFS W25Q128 profile can wait up to 3 ms for page program and up to
2 seconds for its selected 64 KiB erase. That behavior is incompatible with the
flight scheduler.

The new backend uses the W25Q128 commands directly:

| Operation | Unit | Runtime behavior |
| --- | ---: | --- |
| Read status `0x05` | 1 byte | One bounded FlexSPI2 IP transaction |
| Page program `0x02` | 256 B | Command/data submitted, WIP polled on later ticks |
| Sector erase `0x20` | 4 KiB | Command submitted, WIP polled on later ticks |
| Read `0x03` | up to 256 B | Used for header scan and post-program verification |

The FlexSPI2 IP transaction itself has a 1 ms timeout. This is a controller
command bound, not permission to wait for NOR program or erase completion.

### 4.1 Sector layout

W25Q128 is divided into 4096 circular 4 KiB sectors. Each sector contains one
header page and fifteen data pages.

```text
4 KiB sector
    page 0: SectorHeader + 0xFF padding
    page 1..15: PageHeader + up to 240 stream bytes + 0xFF padding
```

`SectorHeader`, 16 bytes, packed little-endian:

```text
magic                 uint32  0x4E534543, "NSEC"
sector_sequence       uint32
first_stream_offset   uint32
version               uint16  1
crc16                 uint16  CRC of header with this field zero
```

`PageHeader`, 16 bytes, packed little-endian:

```text
magic                 uint32  0x4E504147, "NPAG"
stream_offset         uint32
payload_length        uint16  1..240
payload_crc16         uint16
header_crc16          uint16  CRC of header with this field zero
version               uint8   1
flags                 uint8   reserved
```

The page is consumed from RAM only after WIP clears and a complete 256-byte
read-back equals the submitted page. A torn page is rejected by its header or
payload CRC at the next boot.

### 4.2 Circular retention and erase-ahead

Sector sequence numbers order the circular journal. At boot, only 4096 sector
headers and the newest sector's data pages are scanned. The next valid page and
logical stream offset are then recovered.

Two erased sectors are maintained ahead of the active write sector. Erase is an
asynchronous state:

```text
IDLE -> issue 4 KiB erase -> ERASE_BUSY
ERASE_BUSY -> one status poll per logger tick
ready -> verify erased header bytes -> IDLE
```

At 4.86 kB/s, one sector carries 3600 logical bytes, or about 0.74 seconds of
data. Two erased sectors therefore provide about 1.48 seconds of write reserve.
The 8 KiB backend queue absorbs a worst-case 4 KiB erase interval while sensor
and FSM tasks continue running.

When the physical ring wraps, the next oldest sector is erased and reused. Once
GROUND flushing is requested, speculative erase-ahead stops. Only queued data
is programmed, preserving the final flight record.

Effective QSPI logical capacity is approximately 14.75 MB after headers and
padding, or about 50 minutes at the current periodic rate.

## 5. microSD journal file

The SD backend mounts the Teensy built-in SDIO interface with
`SdioConfig(FIFO_SDIO)`. DMA mode is intentionally not used: the bundled SdFat
DMA path waits for DMA completion inside the call, while FIFO mode permits one
sector to be loaded into the SDHC FIFO and completed by the controller/card in
the background.

At init, `/NURA_LOG/MMDDhhmm.NLG` is created from the firmware compilation
timestamp and preallocated to 16 MiB. For example, a compilation at August 8,
01:00 creates `/NURA_LOG/08080100.NLG`. If that exact name already exists, the
logger preserves it and uses `/NURA_LOG/MMDDhhmm_001.NLG`, then increments the
suffix as needed. This avoids overwriting a prior boot from the same firmware
build. Cluster allocation metadata is synchronized before the scheduler starts.

Preallocated FAT clusters can contain old bytes, and the file cannot be safely
truncated or closed without a potentially blocking metadata sync. Therefore the
file is a sequence of self-validating 512-byte blocks rather than a naked frame
stream.

`BlockHeader`, 24 bytes, packed little-endian:

```text
magic                 uint32  0x4E534442, "NSDB"
session_id            uint32
block_sequence        uint32
stream_offset         uint32
payload_length        uint16  1..488
payload_crc16         uint16
header_crc16          uint16  CRC of header with this field zero
version               uint8   1
flags                 uint8   reserved
```

The remaining 488 bytes contain the logical stream and `0xFF` padding. The
session ID is derived from build time, file index and boot-time microseconds.
The decoder accepts only contiguous block sequence and stream offsets belonging
to the session in block zero. Stale preallocated cluster contents are ignored.

Runtime write sequence:

```text
if file.isBusy():
    return immediately
if at least 488 queued bytes, or final GROUND flush has a partial block:
    build one 512-byte CRC block
    file.write(block, 512)
    return
```

The 16 MiB boundary is enforced. The backend faults instead of extending the
file and causing an in-flight FAT allocation. It carries approximately 15.98 MB
of logical payload, or roughly 55 minutes at the current periodic rate.

An SD busy interval longer than 1200 ms marks only the SD backend failed. The
value is below the approximately 1.6-second SD queue capacity at nominal rate;
it must be checked against the exact flight SD card during qualification.

## 6. Mirror and failure policy

Both QSPI and SD are required during initialization in the current flight build.
After initialization they fail independently:

- one backend failure disables only that backend;
- the surviving backend continues accepting the logical stream;
- `storageOk` becomes false only when every persistent backend is offline;
- storage failure never changes the flight state or recovery decision;
- transient backpressure pauses upstream draining instead of immediately
  creating different streams on SD and QSPI;
- if all RAM buffering is exhausted, the 16 KiB producer FIFO drops the oldest
  complete records and increments its drop counter.

QSPI faults on controller-command timeout, media-operation timeout, erase
verification failure, or page read-back mismatch. SD faults on write failure,
preallocated boundary exhaustion, or the bounded busy timeout.

## 7. GROUND finalization

GROUND finalization is itself asynchronous:

1. enqueue `GROUND_STOP` once;
2. stop generating FAST/SLOW records;
3. move a bounded number of remaining frames to backend queues each tick;
4. request backend flush when the producer FIFO is empty;
5. QSPI writes one final partial page and SD writes one final padded block;
6. wait through normal `service()` polls until both active backends are idle;
7. mark logging stopped.

No unbounded drain loop, `File.flush()`, FAT truncate, FAT close, or LittleFS
sync is executed from the GROUND transition.

The boot composition root prewarms both stores before sensor bring-up because
the current PCB has shown SDIO sensitivity to later bus initialization. It
explicitly checks the SD backend and enters the storage panic path when the SD
session is not healthy. The task checks the already-open storage first and
never repeats preallocation or journal scanning during its own `init()`.

## 8. Record classes

### FAST, 20 ms

- FSM state and health flags
- low-g acceleration, gyro, R/P/Y and tilt
- high-g raw counts and acceleration
- barometer pressure, raw altitude and filtered altitude
- battery voltage and decision sequence

### SLOW, 100 ms

- magnetometer raw and converted values
- GPS position, altitude, speed, course, HDOP and satellites
- GPS parser counters
- barometer fault flags and counters

### EVENT

- boot and logger initialization
- every FSM transition
- storage fault
- final ground stop

### DECISION

- launch and burnout evidence
- apogee predictor quality and confirmation
- descent, tilt and timer fallback evidence
- main deployment and landing evidence

State transitions and decisions are source-queued. They are not inferred by
polling and therefore are not lost when multiple decisions occur in one logger
period.

## 9. Recovery tooling

`tools/decode_flight_log.py` auto-detects three inputs:

1. SD `NSDB` block file
2. raw W25Q128 `NSEC`/`NPAG` dump
3. plain logical `.NLG` frame stream

For SD it selects the current session and validates every block. For QSPI it
orders sectors and pages by sequence/stream offset and discards torn pages. It
then decodes only application frames with a valid frame CRC.

## 10. Implementation map

| Responsibility | File |
| --- | --- |
| Frame format and CRC | `src/logging/flight_log_record.*` |
| 16 KiB complete-record FIFO | `src/logging/flight_log_ram_buffer.*` |
| Per-backend 8 KiB byte queue | `src/logging/flight_log_byte_queue.*` |
| Async storage interface and mirror | `src/logging/flight_log_storage.h`, `flight_log_mirror_storage.*` |
| W25Q128 bounded FlexSPI command HAL | `src/hal/w25q128_qspi_hal.*` |
| QSPI raw circular journal | `src/logging/program_flash_flight_log_storage.*` |
| SDIO preallocated block journal | `src/logging/sd_flight_log_storage.*` |
| Producer and async GROUND drain | `src/missions/flight_log_task.*` |
| Host decoder | `tools/decode_flight_log.py` |
| Host tests | `test/logging/*` |
| Hardware end-to-end test | full `main`/`debug_no_lora` firmware path |

## 11. Verification and flight acceptance

Completed software checks:

- frame CRC and FIFO overflow tests
- backend byte-queue wrap test
- mirror degradation test
- SD and QSPI wrapper decoder tests, including corrupted payload rejection
- `main` firmware build
- `debug_no_lora` firmware build

Required on the final board and selected SD card:

1. Run `debug_no_lora`; validate SD block CRCs and QSPI page CRCs.
2. Measure every `flight_log` tick with microsecond resolution during QSPI erase,
   QSPI rollover, SD write, and SD busy intervals.
3. Proposed release gate: logger tick maximum below 5 ms. This leaves at least
   half of the 10 ms FSM period; it is an engineering acceptance proposal and
   must be confirmed with measured hardware results.
4. Run at twice nominal production rate for at least ten minutes with zero RAM
   record drops.
5. Remove or stall SD during logging and verify QSPI continues without a missed
   FSM/sensor period.
6. Force QSPI timeout and verify SD continues.
7. Cut power repeatedly during page program, sector erase, SD transfer and
   GROUND drain. The decoder must recover every complete block/page/frame before
   the torn unit and must not emit stale preallocated SD data.
8. Fill and wrap the complete QSPI journal and verify monotonically ordered
   recovery of the retained window.

This implementation is not flight-qualified until the hardware latency and
power-interruption tests above are recorded.

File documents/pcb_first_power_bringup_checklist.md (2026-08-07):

# NURA 에비오닉스 PCB 최초 전원 인가 Bring-Up 체크리스트

상태: 하드웨어 bring-up 체크리스트  
대상: 모든 센서가 실장된 신규 PCB 조립체  
작성일: 2026-06-26  

## 절대 안전 규칙

이 체크리스트를 수행하는 동안 e-match, 니크롬선, 사출 화약, 기타
에너지를 가진 부하를 절대 연결하지 않는다.

`J_PYRO1`과 `J_PYRO2`는 전원, 도통, 펌웨어, 오실로스코프, 더미 부하
테스트가 모두 통과할 때까지 반드시 비워둔다. 최초 전원 인가 테스트는
보드 상태 확인 테스트이지, 사출 테스트가 아니다.

## 현재 보드에 대한 전제

### Pyro 커넥터 및 MOSFET 구조

Pyro 커넥터 구조는 다음과 같이 본다.

| 커넥터 | 핀 / 넷 | 예상 역할 |
| --- | --- | --- |
| `J_PYRO1` pin 1 | `+BATT_ARMED` | Pyro 부하로 들어가는 arming 이후 배터리 전원 |
| `J_PYRO1` pin 2 | `/PYRO1_2` | Pyro 1 MOSFET drain 쪽 |
| `J_PYRO2` pin 1 | `+BATT_ARMED` | Pyro 부하로 들어가는 arming 이후 배터리 전원 |
| `J_PYRO2` pin 2 | `/PYRO2_2` | Pyro 2 MOSFET drain 쪽 |

관측/추정되는 MOSFET 묶음은 다음과 같다.

| 채널 | 회수 역할 | MOSFET | MCU 출력 쌍 |
| --- | --- | --- | --- |
| Pyro 1 | Drogue | `Q1`, `Q2` 병렬 구동 | `D28`, `D29` |
| Pyro 2 | Main | `Q3`, `Q4` 병렬 구동 | `D35`, `D38`로 이동됨 |

중요: Pyro 2는 기존 `D36`/`D37` 쌍에서 이동했다. 신규 보드 bring-up
기준은 다음과 같다.

```text
Pyro 2 output pair: D35 and D38
Pyro 2 sense: D41
```

Pyro 2의 정확한 `gpio1`/`gpio2` 순서는 펌웨어에서 실제 출력을 켜기 전,
Teensy 핀에서 MOSFET gate/driver 입력 넷까지 도통을 찍어서 확인해야
한다. 이 확인이 끝나기 전까지는 다음과 같이 기록한다.

```text
Pyro2 GPIO pair = {D35, D38}
Pyro2 gpio1/gpio2 order = 하드웨어 도통 확인 TODO
```

### LoRa Reset/RXE 구조

현재 PCB 이해 기준으로 SX1262 LoRa reset net은 Teensy가 제어하지 않는다.

확인된 구조:

- `U7` LoRa `RST`는 `R2`를 통해 `+3V3_LORA`로 pull-up된다.
- `JP2`는 `LORA_RST`를 GND로 당길 수 있다.
- `JP2`가 실수로 쇼트되어 있으면 SX1262는 영원히 reset 상태에 머문다.
- `RXE`는 Teensy `D30`에 연결된 별도의 RF 제어 넷이다.

펌웨어 관점의 의미:

| Net | PCB | 현재 코드 리스크 |
| --- | --- | --- |
| `LORA_RST` | R2 pull-up, JP2-to-GND 옵션 | 실제 MCU reset net이 발견되지 않는 한 코드에서는 no-reset 상태로 유지해야 함 |
| `RXE` | Teensy `D30` | 전체 LoRa 테스트 전 `board_pinmap.h`에서 `rxEnablePin = 30`으로 지정해야 함 |

### LoRa SPI1 배선

| SX1262 net | Teensy pin |
| --- | --- |
| `SO` / MISO | `D1` |
| `SI` / MOSI | `D26` |
| `SCK` | `D27` |
| `NSS` | `D9` |
| `RXE` | `D30` |
| `DIO1` | `D31` |
| `BUSY` | `D32` |

과거 실패 모드: LoRa MISO가 GND와 쇼트된 적이 있다. `U7` SO/MISO와 GND
사이가 0옴에 가깝게 측정되면 보드에 전원을 넣지 않는다.

### LIS3MDL 실장 관련 주의

현재 보드는 LIS3MDL이 미실장된 상태로도 테스트할 수 있다. 나중에
LIS3MDL을 실장한다면, `0x1C`로 응답할 것이라고 가정하기 전에 I2C
strap net을 반드시 확인한다.

알려진 우려:

- 이전 수작업 배선에서는 `CS = 3.3 V`, `DO/SDO = GND`가 필요했다.
- Gerber 검토상 `DO`, `CS`, 위쪽 GND pad 하나가 unconnected일 가능성이
  있었다.
- 이 strap들이 실제로 연결되어 있지 않으면 LIS3MDL이 기대한 I2C
  mode/address로 고정되지 않을 수 있다.

I2C1 버스 자체에는 pull-up(`R23`, `R24`)이 있으므로, LIS3MDL이 없어도
SDA/SCL floating 문제는 줄어들 가능성이 있다.

## 전체 기능 테스트 전 수정해야 할 펌웨어/PCB 불일치

모든 하드웨어를 실제로 사용하는 빌드를 돌리기 전에 다음 코드 매핑을
수정하거나 확인해야 한다.

| 기능 | PCB / 수정된 보드 | 현재 리스크 |
| --- | --- | --- |
| Pyro 2 output pair | `D35`, `D38` | `include/board_pinmap.h`에서 Pyro2 GPIO가 아직 unassigned일 수 있음 |
| Pyro 2 sense | `D41` | 도통 확인 시 `D41`으로 유지해야 함 |
| LoRa RXE | `D30` | `Sx1262LoRa::rxEnablePin`이 아직 `kUnassignedPin`일 수 있음 |
| LoRa reset | MCU reset 없음; R2 pull-up / JP2 GND | `D30`을 reset으로 매핑하면 안 됨 |

Pyro2 순서 확인과 dummy-load 테스트가 끝날 때까지
`NURA_ENABLE_PYRO_OUTPUTS`를 정의하지 않는다.

## 필요 장비

- 도통/저항 모드와 DC 전압 모드가 있는 디지털 멀티미터.
- 최초 외부 전원 테스트용 전류 제한 가능 bench supply.
- 오실로스코프. 가능하면 2채널 이상.
- Teensy serial/programming용 USB 케이블.
- 이후 pyro bench test용 dummy load. 최초 전원 인가에는 사용하지 않음.
- 에너지 부하 없음.

최초 보드 단독 전원 테스트의 권장 bench supply 제한:

```text
시작 전압: 의도한 low-side safe input 또는 동등한 실험실 전원을 사용
전류 제한: 손상 전 쇼트를 잡을 수 있을 만큼 낮게 시작
전류 제한 상향: rail 검증이 끝난 뒤에만 수행
```

팀의 실제 regulator/current budget이 있으면 그 값을 사용한다. 모르면
보수적으로 시작하고, 전압을 올리는 동안 전류 거동을 계속 관찰한다.

## Phase 0: 계측 전 육안 검사

확인 항목:

- Teensy 핀, LoRa 핀, regulator 핀, MOSFET, pyro connector pad에 납브릿지
  없음.
- Teensy, SX1262, GPS, MPL3115A2, LSM6DSO32, H3LIS331DL, LIS3MDL 실장 시
  방향이 맞음.
- Pyro2 D35/D38 reroute 주변에 copper debris 없음.
- JP2가 실수로 `LORA_RST`를 GND에 쇼트시키고 있지 않음.
- Pyro connector는 비어 있음.
- 배터리/arming switch는 OFF.
- 저항 측정 중 USB는 분리.

실패 기준:

- 전원 rail, LoRa MISO, pyro drain, MOSFET gate 주변에 눈에 보이는 bridge가
  있으면 테스트 중단.
- Pyro2 D35/D38 수정 상태가 불확실하면, 도통으로 net이 증명될 때까지
  pyro-output 관련 테스트 중단.

## Phase 1: 무전원 도통 및 저항 검사

전원은 완전히 분리되어 있어야 한다. USB도 분리한다. 배터리도 분리한다.
특정 단계에서 ON이라고 명시하지 않는 한 arming switch는 OFF 상태여야 한다.

### 전체 전원 rail

저항/도통을 측정한다.

| Probe A | Probe B | 기대 결과 | 중단 조건 |
| --- | --- | --- | --- |
| `+BATT` | GND | 쇼트 아님 | 0옴 근처 |
| `+5V6` | GND | 쇼트 아님 | 0옴 근처 |
| `+5V` | GND | 쇼트 아님 | 0옴 근처 |
| `+3V3` | GND | 쇼트 아님 | 0옴 근처 |
| `+3V3_LORA` | GND | 쇼트 아님 | 0옴 근처 |
| `+BATT` | `+BATT_ARMED`, switch OFF | open / 매우 높은 저항 | 낮은 저항 |
| `+BATT` | `+BATT_ARMED`, switch ON | F1/switch 경로로 연결 | 연결되어야 할 때 open |

해석:

- capacitor가 멀티미터 전류로 잠깐 충전되면서 저항값이 변할 수 있다.
  안정적으로 0옴에 가까운 값이 유지되는 것이 위험 신호다.
- 단순 pass/fail만 쓰지 말고 대략적인 저항값도 기록한다.

### Pyro connector 쇼트 검사

e-match/니크롬은 연결하지 않는다.

| Probe A | Probe B | 기대 결과 |
| --- | --- | --- |
| `J_PYRO1` pin 1 / `+BATT_ARMED` | GND | 쇼트 없음 |
| `J_PYRO1` pin 2 / `/PYRO1_2` | GND | hard 0옴 쇼트 없음 |
| `J_PYRO2` pin 1 / `+BATT_ARMED` | GND | 쇼트 없음 |
| `J_PYRO2` pin 2 / `/PYRO2_2` | GND | hard 0옴 쇼트 없음 |
| `J_PYRO1` pin 1 | `J_PYRO1` pin 2 | 부하 없을 때 open |
| `J_PYRO2` pin 1 | `J_PYRO2` pin 2 | 부하 없을 때 open |

어떤 pyro connector pin이라도 GND나 반대쪽 pyro connector pin과 예상치 않게
hard-short되어 있으면 즉시 중단한다.

### Pyro MOSFET gate/MCU 매핑

펌웨어 핀맵을 수정하거나 출력을 enable하기 전에 수행한다.

| Net / point | 예상 매핑 |
| --- | --- |
| Pyro 1 gate/input A | Teensy `D28` |
| Pyro 1 gate/input B | Teensy `D29` |
| Pyro 1 sense | Teensy `D25` |
| Pyro 2 gate/input A | `D35` 또는 `D38` 중 하나 |
| Pyro 2 gate/input B | `D35` 또는 `D38` 중 나머지 하나 |
| Pyro 2 sense | Teensy `D41` |

정확한 결과를 다음 형식으로 기록한다.

```text
Pyro2 gpio1 = D__
Pyro2 gpio2 = D__
Pyro2 sense = D41 확인됨 / 미확인
```

layout 모양만 보고 gpio1/gpio2 순서를 추측하지 않는다. Teensy pad/header에서
MOSFET gate/driver net까지 도통으로 확인한다.

### LoRa reset 및 SPI net

| Probe A | Probe B | 기대 결과 | 중단 조건 |
| --- | --- | --- | --- |
| `LORA_RST` | GND | 쇼트 없음 | 0옴 근처 |
| `LORA_RST` | `+3V3_LORA` | `R2`를 통한 저항 경로 | hard short 또는 R2가 있어야 하는데 open |
| `U7` SO/MISO pin | GND | 쇼트 없음 | 0옴 근처 |
| `U7` SO/MISO pin | Teensy `D1` | 도통 | open |
| `U7` SI/MOSI pin | Teensy `D26` | 도통 | open |
| `U7` SCK pin | Teensy `D27` | 도통 | open |
| `U7` NSS pin | Teensy `D9` | 도통 | open |
| `U7` BUSY pin | Teensy `D32` | 도통 | open |
| `U7` DIO1 pin | Teensy `D31` | 도통 | open |
| `RXE` net | Teensy `D30` | 도통 | open |

반드시 반복 확인해야 할 핵심 항목:

```text
LoRa MISO / U7 SO / Teensy D1은 GND와 쇼트되어 있으면 안 된다.
```

### I2C net

| Bus | Net | 기대 결과 |
| --- | --- | --- |
| I2C0 | SDA `D18` to GND | 쇼트 없음 |
| I2C0 | SCL `D19` to GND | 쇼트 없음 |
| I2C1 | SDA `D17` to GND | 쇼트 없음 |
| I2C1 | SCL `D16` to GND | 쇼트 없음 |
| I2C0 | SDA/SCL to `+3V3` | `R21/R22`를 통한 pull-up 저항 경로 |
| I2C1 | SDA/SCL to `+3V3` | `R23/R24`를 통한 pull-up 저항 경로 |

### SPI0 센서 net

| Net | 예상 매핑 |
| --- | --- |
| SPI0 MISO | Teensy `D12`, LSM/H3L 공유 |
| SPI0 MOSI | Teensy `D11` |
| SPI0 SCK | Teensy `D13` |
| LSM CS | Teensy `D10` |
| H3L CS | Teensy `D0` |

모든 SPI0 data line과 두 CS line은 GND 또는 `+3V3`에 쇼트되어 있으면 안 된다.

### UART/GPS net

| Net | 예상 매핑 |
| --- | --- |
| GPS TXD | Teensy RX3 `D15` |
| GPS RXD | Teensy TX3 `D14` |

두 UART line 모두 GND 또는 3.3 V와 쇼트되어 있지 않은지 확인한다.

## Phase 2: 펌웨어 하드웨어 구동 없이 최초 전원 인가

조건:

- Pyro connector는 비어 있음.
- `+BATT_ARMED` 확인을 제외하면 arming switch는 OFF.
- Bench supply는 current limit 설정.
- 최초 DC rail 측정 시 USB는 분리해도 된다.

전원 인가 후 관찰:

| 테스트 | 기대 결과 |
| --- | --- |
| Bench supply current | 갑작스러운 current-limit hit 없음 |
| Regulator 온도 | 빠른 발열 없음 |
| `+5V6` | 예상 regulator 출력, 안정적 |
| `+5V` | 예상 5 V rail, 안정적 |
| `+3V3` | 약 3.3 V, 안정적 |
| `+3V3_LORA` | LoRa rail이 enable된 경우 약 3.3 V |
| `+BATT_ARMED`, switch OFF | `+BATT`와 연결되지 않음 |
| `+BATT_ARMED`, switch ON | 보호/arming battery path를 따라감 |

중단 조건:

- 어떤 rail이라도 collapse.
- 전원이 current limit에 걸림.
- regulator, MOSFET, LoRa module, 센서 중 하나라도 뜨거워짐.
- switch OFF 상태여야 하는데 `+BATT_ARMED`가 살아 있음.

## Phase 3: 전원 인가 후 DC 핀 전압 검사

보드 GND 기준으로 측정한다.

### LoRa

| Net | 펌웨어 toggle 전 기대 DC level |
| --- | --- |
| `+3V3_LORA` | 약 3.3 V |
| `LORA_RST` | R2 pull-up을 통해 약 3.3 V |
| `JP2` GND side | 0 V |
| `NSS` / D9 | firmware init 이후 보통 idle high, init 전에는 미정 |
| `BUSY` / D32 | idle 시 low, radio busy 구간에서 high |
| `DIO1` / D31 | 보통 idle low |
| `RXE` / D30 | 펌웨어에 따라 다름. LoRa 테스트 중 반드시 확인 |
| MISO / D1 | 0 V에 붙어 있지 않음. 쇼트 없음 |

`LORA_RST`가 0 V라면 JP2 쇼트 또는 납브릿지를 의심한다.

### I2C

| Net | 기대 idle 전압 |
| --- | --- |
| I2C0 SDA D18 | idle 약 3.3 V |
| I2C0 SCL D19 | idle 약 3.3 V |
| I2C1 SDA D17 | idle 약 3.3 V |
| I2C1 SCL D16 | idle 약 3.3 V |

idle이 0 V 근처이면 hard short 또는 stuck device를 의심한다. idle이 중간
전압이면 약한 pull-up, 잘못된 전원 rail, partial short, 전원 미인가 device
leakage를 의심한다.

### SPI0

센서 펌웨어가 돌기 전 SPI line은 조용할 수 있다. 펌웨어 probe 중에는:

| Net | 기대 결과 |
| --- | --- |
| D13 SCK | SPI transfer 중 burst |
| D11 MOSI | transfer 중 burst |
| D12 MISO | WHOAMI/read 중 응답 activity |
| D10 LSM CS | idle high, LSM transaction 중 low |
| D0 H3L CS | idle high, H3L transaction 중 low |

### 부하 없는 Pyro 출력

Pyro load를 연결하지 않는다.

펌웨어에서 physical pyro output이 disabled인 경우:

| Net | 기대 결과 |
| --- | --- |
| Pyro1 D28/D29 | flight logic 때문에 능동 pulse가 나오면 안 됨 |
| Pyro2 D35/D38 | flight logic 때문에 능동 pulse가 나오면 안 됨 |
| J_PYRO1 pin 2 | 예상치 못한 low-side hard-on 없음 |
| J_PYRO2 pin 2 | 예상치 못한 low-side hard-on 없음 |

이후 명시적인 bench-only GPIO test build를 사용하고 에너지 부하가 없는 경우:

- D28/D29와 D35/D38을 scope로 본다.
- 먼저 idle 상태를 확인한다.
- 제어된 bench test에서만 pulse width가 `PYRO_FIRE_DURATION_MS`와 일치하는지
  확인한다.
- 이 단계에서는 battery-fed pyro load를 연결하지 않는다.

## Phase 4: 오실로스코프 테스트

보드 GND spring 또는 짧은 ground lead를 사용한다. 긴 ground clip은 빠른
SPI edge를 실제보다 나쁘게 보이게 만들 수 있다.

### 전원 rail

Scope 대상:

| Rail | 확인 항목 |
| --- | --- |
| `+3V3` | sensor init 및 SD write 중 ripple |
| `+3V3_LORA` | LoRa init/TX 중 droop/ripple |
| `+5V` | SD write 및 buzzer 중 droop |
| `+BATT_ARMED` | arming switch OFF일 때 예상치 못한 pulse 없음 |

정량 acceptance target은 프로젝트별로 정해야 하지만, 정성적으로는:

- MCU reset을 유발할 큰 dip 없음.
- regulator rail oscillation 없음.
- RF TX로 인한 brownout 없음.

### I2C0 / I2C1

I2C scanner 또는 sensor init을 돌리면서 SDA/SCL을 scope로 본다.

기대 결과:

- Idle high가 3.3 V 근처.
- Low pulse가 0 V 근처까지 깨끗하게 내려감.
- 펌웨어가 바꾸지 않는 한 SCL은 설정된 100 kHz 근처.
- 기대 address에서 ACK bit가 존재:
  - MPL3115A2: I2C0의 `0x60`.
  - LIS3MDL: 실장되어 있고 strap이 맞으면 I2C1의 `0x1C`.

실패 패턴:

- SDA stuck low: device가 bus를 잡고 있음, short, 잘못된 power sequencing.
- SCL stuck low: short 또는 device stretch/fault.
- 둘 다 중간 전압: pull-up 또는 leakage 문제.

### SPI0 센서

센서 펌웨어 실행 중 D13, D11, D12, D10, D0를 scope로 본다.

기대 결과:

- D13 SCK burst.
- 한 번에 하나의 CS만 low.
- read 중 MISO D12가 변화.
- LSM WHOAMI가 기대 LSM6DSO32 값으로 확인.
- H3L WHOAMI가 `0x32`로 확인.

실패 패턴:

- 두 CS가 동시에 low: firmware/pin fault.
- MISO가 0 V flat: short 또는 unpowered sensor.
- MISO가 3.3 V flat: device response 없음, pull-up/leakage, wrong mode.
- MISO가 중간 전압: contention 또는 partial short.

### SPI1 LoRa

LoRa init 중 D27, D26, D1, D9, D30, D31, D32를 scope로 본다.

기대 결과:

- NSS D9는 idle high, command 중 low.
- SCK D27은 command 중 burst.
- MOSI D26은 command byte를 전달.
- MISO D1은 register/status read 중 constant가 아닌 데이터를 반환.
- BUSY D32는 SX1262 command timing에 따라 전이.
- DIO1 D31은 IRQ 전까지 low 유지.
- RXE D30은 firmware가 매핑된 뒤 설정된 RF path 동작을 따라감.

LoRa 세부 acceptance check:

1. `LORA_RST`가 high 유지.
2. `BUSY`가 영원히 high에 stuck되지 않음.
3. MISO가 0 V가 아니고, 쇼트가 아니며, 모든 transfer에서 flat하지 않음.
4. SX1262 init이 최소 10/10 cold 또는 reset cycle에서 반복 성공.
5. Downlink packet이 동일 frequency/BW/SF/CR/sync word를 쓰는 SX1276 지상국에
   수신됨.

### Pyro GPIO 오실로스코프 테스트

모든 rail, 센서, 로깅, LoRa 확인이 끝난 뒤에만 수행한다.

준비:

- e-match 없음.
- 니크롬 없음.
- 최초 GPIO-only scope test에서는 pyro battery feed도 없는 쪽을 권장.
- bench-only firmware build 사용.
- 명시적인 테스트에서만 `NURA_ENABLE_PYRO_OUTPUTS` 정의.

Scope 대상:

| 채널 | 오실로스코프로 볼 핀 |
| --- | --- |
| Pyro 1 / Drogue | D28, D29, J_PYRO1 pin 2 |
| Pyro 2 / Main | D35, D38, J_PYRO2 pin 2 |

기대 결과:

- Boot 이후 출력 idle OFF.
- `SAFE`, `GROUND`, `FAULT`는 모든 출력을 OFF로 강제.
- Pyro1 sequence는 제어된 drogue test path에서만 D28/D29 pulse.
- Pyro2 sequence는 제어된 main test path에서만 D35/D38 pulse.
- telemetry, USB, SD dump, packet parsing만으로 어떤 채널도 fire되지 않음.

중단 조건:

- 어떤 pyro output이라도 init 중 예상치 않게 pulse.
- Pyro2 새 D35/D38이 아니라 기존 D36/D37이 pulse.
- D22 battery sense가 pyro output 상태와 상호작용.

## Phase 5: 권장 펌웨어 테스트 순서

### 1. 전원 전용 smoke firmware

목표: pyro를 건드리지 않고 USB serial과 기본 보드 전원을 확인.

기대 결과:

- Teensy가 USB serial로 enumerate.
- 필요하면 buzzer/LED 테스트 가능.
- LoRa 또는 pyro output이 구동되지 않음.

### 2. I2C scanner

기대 결과:

| Bus | 기대 device |
| --- | --- |
| I2C0 D18/D19 | MPL3115A2 at `0x60` |
| I2C1 D17/D16 | LIS3MDL이 실장된 경우에만 `0x1C` |

### 3. SPI0 sensor probe

기대 결과:

- H3LIS331DL WHOAMI `0x32`.
- LSM6DSO32 WHOAMI 기대값.
- CS line은 idle high이고 서로 overlap되지 않음.

### 4. microSD logging

기대 결과:

- SD가 안정적으로 초기화.
- `/NURA_LOG/MMDDhhmm.NLG` 생성(동일 컴파일 시각 파일이 있으면 `_001` suffix).
- Parsed log에 BOOT, state event, FAST/SLOW frame 포함.

### 5. Program/QSPI flash logging

기대 결과:

- W25Q128 또는 선택된 flash read/write verify가 반복 통과.
- Flight logger primary storage가 append/rotate를 수행해도 SD mirror를
  corrupt하지 않음.

### 6. LoRa init and downlink

이 테스트 전 firmware pinmap 수정:

```cpp
Sx1262LoRa::rxEnablePin = 30U
Sx1262LoRa::resetPin = -1
```

기대 결과:

- `LORA_RST` high.
- SX1262 init 10/10 성공.
- 지상 SX1276이 유효한 NURA packet 수신.
- SPI1 timing이 sensor/FSM task period를 밀지 않음.

### 7. Pyro GPIO-only bench test

이 테스트 전 도통으로 순서를 확인한 뒤 firmware pinmap 수정:

```cpp
Pyro2::gpio1Pin = D35 또는 D38, 도통 확인 결과 기준
Pyro2::gpio2Pin = 나머지 핀
Pyro2::sensePin = D41
```

기대 결과:

- 부하 없음.
- 먼저 scope-only 또는 LED/dummy logic load 사용.
- `NURA_ENABLE_PYRO_OUTPUTS`는 bench test build에서만 사용.
- Pyro1과 Pyro2는 각자의 명령된 state-machine sequence에서만 pulse.

## Phase 6: Acceptance 기록 양식

모든 보드 테스트를 다음 형식으로 기록한다.

```text
보드 serial / 식별자:
날짜:
작업자:
전원 source:
전류 제한:
배터리 / bench 전압:

무전원 저항:
  +BATT-GND:
  +5V6-GND:
  +5V-GND:
  +3V3-GND:
  +3V3_LORA-GND:
  +BATT to +BATT_ARMED switch OFF:
  +BATT to +BATT_ARMED switch ON:

부하 없는 Pyro connector:
  J_PYRO1 pin1-GND:
  J_PYRO1 pin2-GND:
  J_PYRO1 pin1-pin2:
  J_PYRO2 pin1-GND:
  J_PYRO2 pin2-GND:
  J_PYRO2 pin1-pin2:

Pyro2 reroute 도통:
  D35 연결 대상:
  D38 연결 대상:
  D41 sense 확인:

LoRa:
  LORA_RST-GND:
  LORA_RST-3V3_LORA:
  U7 MISO-GND:
  U7 MISO-D1:
  BUSY-D32:
  DIO1-D31:
  RXE-D30:

전원 인가 후 rail:
  +5V6:
  +5V:
  +3V3:
  +3V3_LORA:
  +BATT_ARMED OFF:
  +BATT_ARMED ON:

오실로스코프:
  I2C0 idle/speed/ACK:
  I2C1 idle/speed/ACK:
  SPI0 LSM/H3L:
  SPI1 LoRa:
  SD write rail droop:
  LoRa TX rail droop:

펌웨어:
  I2C scanner:
  SPI0 sensor probe:
  SD log parse:
  Flash verify:
  LoRa init 10/10:
  LoRa packet RX:
  Pyro GPIO-only scope:

결과:
남은 이슈:
해결 전 비행 금지:
```

## 중단 후 수정 조건

다음 중 하나라도 참이면 다음 phase로 넘어가지 않는다.

- 어떤 power rail이라도 GND와 쇼트.
- 어떤 pyro connector pin이라도 예상치 않게 쇼트.
- Pyro2 D35/D38 mapping을 모르는 상태에서 output firmware를 enable하려 함.
- `LORA_RST` stuck low.
- LoRa MISO가 GND와 쇼트.
- I2C SDA/SCL stuck low.
- SPI MISO가 확인된 short 또는 bus contention 때문에 flat.
- USB/external power 상호작용으로 reset 또는 reverse-power 증상 발생.
- 테스트에서 microSD logging이 필요한데 실패.
- 명시적인 bench GPIO test 밖에서 어떤 pyro output이라도 상태 변화.

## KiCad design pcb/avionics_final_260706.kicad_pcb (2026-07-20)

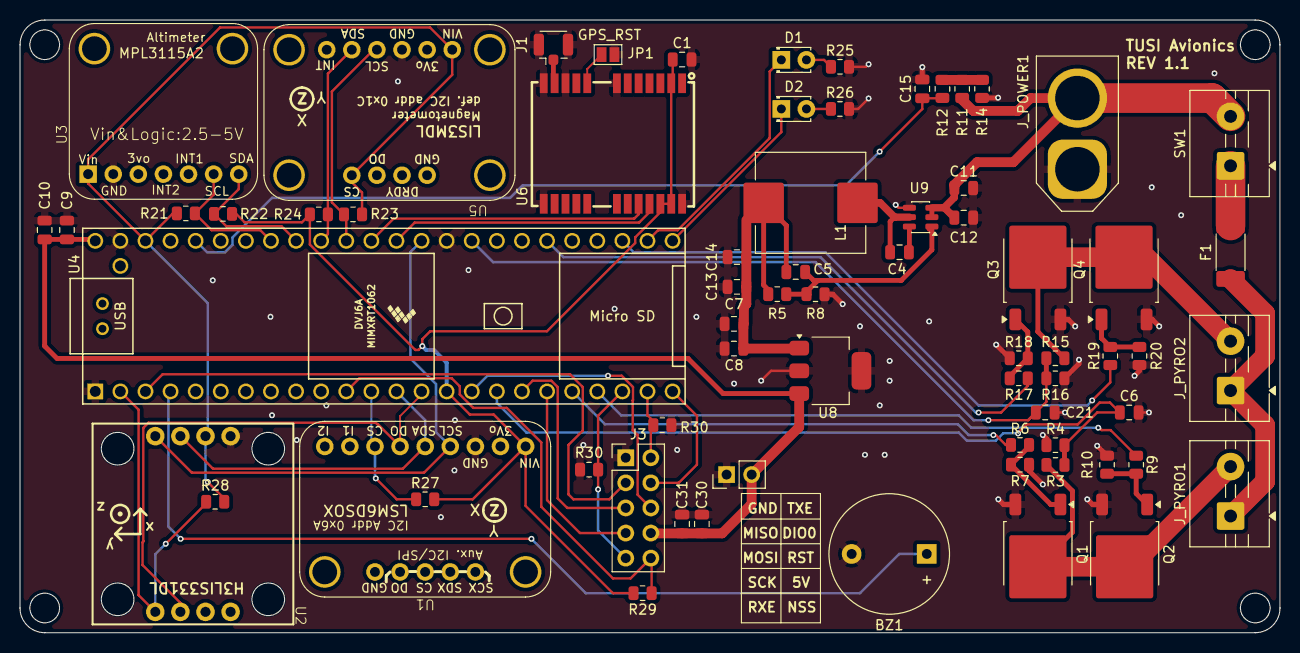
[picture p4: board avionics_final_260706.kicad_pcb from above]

Board: 2 copper layers, 127.5 x 62.0 mm, 69 parts (0 on the bottom side), 49 nets.

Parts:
BZ1: Buzzer; Buzzer_12x9.5RM7.6
C1: 1u; C_0805_2012Metric
C4, C6, C7, C9, C11, C15, C21, C30: 100n; C_0805_2012Metric
C5: 100p; C_0805_2012Metric
C8, C31: 10u; C_0805_2012Metric
C10, C12, C13, C14: 22u; C_0805_2012Metric
D1, D2: LED; LED_D1.8mm_W3.3mm_H2.4mm
F1: 5A; Fuse_2410_6127Metric
J1: U.FL-R-SMT-1(10); U.FL_Hirose_U.FL-R-SMT-1_Vertical
J3: Conn_LoRA; PinHeader_2x05_P2.54mm_Vertical
JP1: GPS_RST; SolderJumper-2_P1.3mm_Open_Pad1.0x1.5mm
J_POWER1: XT60; AMASS_XT60-F_1x02_P7.20mm_Vertical
J_PYRO1, J_PYRO2: IGNITER_5R6; TerminalBlock_MaiXu_MX126-5.0-02P_1x02_P5.00mm
L1: 10uH; L_Changjiang_FXL1050
Q1, Q2, Q3, Q4: IRLR8726; TO-252-2
R3, R15: 330k; R_0805_2012Metric
R4, R16: 68k; R_0805_2012Metric
R5: 180k; R_0805_2012Metric
R6, R9, R17, R19: 100; R_0805_2012Metric
R7, R10, R18, R20, R30, R30#2: 100k; R_0805_2012Metric
R8: 30k; R_0805_2012Metric
R11: 150k; R_0805_2012Metric
R12: 1k; R_0805_2012Metric
R14: 33k; R_0805_2012Metric
R21, R22, R23, R24, R27, R28, R29: 4.7k; R_0805_2012Metric
R25, R26: 220; R_0805_2012Metric
SW1: ARM; TerminalBlock_MaiXu_MX126-5.0-02P_1x02_P5.00mm
U1: Adafruit_LSM6DSO32; LSM6DSOX
U2: Sparkfun_H3LIS331DL
U3: Adafruit_MPC3315A2
U4: Teensy4.1; Teensy41
U5: LIS3MDL; Adafruit_LIS3MDL
U6: NEO-M9N-00B; GPSM-SMD_24P-L16.0-W12.2-P1.10-BL
U8: MCP1826S-5002; SOT-223-3_TabPin2
U9: AP63200WU-7; TSOT-23-6
pinheader: PinHeader_1x02_P2.54mm_Vertical

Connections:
+5V: C9.1, C10.1, C30.1, C31.1, J3.8, U4.48 (VIN), U8.3 (VO), pinheader.2
+5V6: C5.1, C5.2, C7.1, C8.1, C13.1, C14.1, L1.2, R5.1, R5.2, R8.1, U8.1 (VI), U9.1 (FB)
+BATT: C11.1, C12.1, J_POWER1.2, R11.1, SW1.2 (B), U9.2 (EN), U9.3 (IN)
/+3V3: C1.1, R21.1, R22.2, R23.1, R24.2, R27.2, R28.2, R29.2, U1.1 (VIN), U2.2 (3.3v), U3.1 (Vin), U4.15 (3V3), U4.46 (3V3), U5.1 (VIN), U5.10 (CS), U6.2 (D_SEL), U6.22 (V_BCKP), U6.23 (VCC)
/+BATT_ARMED: F1.2, J_PYRO1.1, J_PYRO2.1
/ADC_PYRO1_SENSE: C6.1, R3.1, R4.2, U4.17 (25_A11_RX6_SDA2)
/ADC_PYRO2_SENSE: C21.1, R15.1, R16.2, U4.33 (41_A17)
/BUZZER_PIN: BZ1.1 (+), U4.4 (2_OUT2)
/CS_IMU_HIGHG: R28.1, U2.8 (CS), U4.2 (0_RX1_CRX2_CS1)
/CS_IMU_LOWG: R27.1, U1.7 (CS), U4.12 (10_CS_MQSR)
/GPS_ANT: J1.1 (In), U6.11 (RF_IN)
/GPS_RX: U4.37 (15_A1_RX3_SPDIF_IN), U6.20 (TXD/SPI-MISO)
/GPS_TX: U4.36 (14_A0_TX3_SPDIF_OUT), U6.21 (RXD/SPI-MOSI)
/I2C0_SCL: R21.2, U3.6 (SCL), U4.41 (19_A5_SCL)
/I2C0_SDA: R22.1, U3.7 (SDA), U4.40 (18_A4_SDA)
/I2C1_SCL: R23.2, U4.38 (16_A2_RX4_SCL1), U5.4 (SCL)
/I2C1_SDA: R24.1, U4.39 (17_A3_TX4_SDA1), U5.5 (SDA)
/LED_GPIO1: D1.1 (K), U4.26 (34_RX8)
/LED_GPIO2: D2.1 (K), U4.25 (33_MCLK2)
/LORA_BUSY: J3.2, R30.1, U4.23 (31_CTX3)
/LORA_DIO1: J3.4, U4.24 (32_OUT1B)
/LORA_NSS: J3.10, R29.1, U4.11 (9_OUT1C)
/LORA_RST: J3.6, U4.16 (24_A10_TX6_SCL2)
/LORA_RXE: J3.9, R30#2.1, U4.22 (30_CRX3)
/PYRO1_2: J_PYRO1.2, Q1.2 (D), Q2.2 (D), R3.2
/PYRO1_GPIO1: R6.1, U4.20 (28_RX7)
/PYRO1_GPIO2: R9.1, U4.21 (29_TX7)
/PYRO2_2: J_PYRO2.2, Q3.2 (D), Q4.2 (D), R15.2
/PYRO2_GPIO1: R17.1, U4.30 (38_CS1_IN1)
/PYRO2_GPIO2: R19.1, U4.27 (35_TX8)
/SPI0_MISO: U1.6 (DO), U2.7 (SA0), U4.14 (12_MISO_MQSL)
/SPI0_MOSI: U1.5 (SDA), U2.3 (SDA), U4.13 (11_MOSI_CTX1)
/SPI0_SCK: U1.4 (SCL), U2.4 (SCL), U4.35 (13_SCK_LED)
/SPI1_MISO: J3.3, U4.3 (1_TX1_CTX2_MISO1)
/SPI1_MOSI: J3.5, U4.18 (26_A12_MOSI1)
/SPI1_SCK: J3.7, U4.19 (27_A13_SCK1)
/VBAT_MON: C15.1, R12.2, U4.44 (22_A8_CTX1)
GND: BZ1.2 (-), C1.2, C6.2, C7.2, C8.2, C9.2, C10.2, C11.2, C12.2, C13.2, C14.2, C15.2, C21.2, C30.2, C31.2, J1.2 (Ext), J3.1, JP1.2 (B), J_POWER1.1, Q1.3 (S), Q2.3 (S), Q3.3 (S), Q4.3 (S), R4.1, R7.1, R8.2, R10.1, R14.1, R16.1, R18.1, R20.1, R25.2, R26.2, R30.2, R30#2.2, U1.3 (GND), U2.1 (GND), U3.2 (GND), U4.1 (GND), U4.34 (GND), U4.47 (GND), U5.3 (GND), U6.7 (V_USB), U6.10 (GND), U6.12 (GND), U6.13 (GND), U6.24 (GND), U8.2 (GND), U9.4 (GND), pinheader.1
unnamed: D1.2 (A), R25.1
unnamed: D2.2 (A), R26.1
unnamed: JP1.1 (A), U6.8 (RESET_N)
unnamed: Q1.1 (G), R6.2, R7.2
unnamed: Q2.1 (G), R9.2, R10.2
unnamed: Q3.1 (G), R17.2, R18.2
unnamed: Q4.1 (G), R19.2, R20.2
unnamed: R11.2, R12.1, R14.2
unnamed: F1.1, SW1.1 (A)
unnamed: C4.2, U9.6 (BST)
unnamed: C4.1, L1.1, U9.5 (SW)

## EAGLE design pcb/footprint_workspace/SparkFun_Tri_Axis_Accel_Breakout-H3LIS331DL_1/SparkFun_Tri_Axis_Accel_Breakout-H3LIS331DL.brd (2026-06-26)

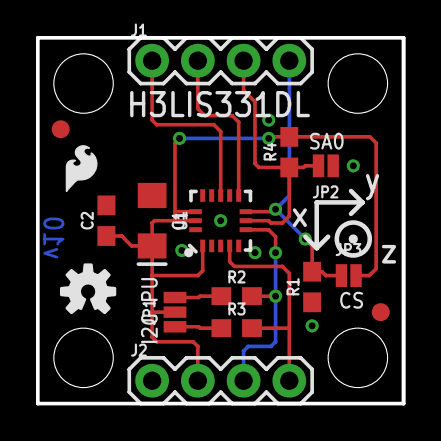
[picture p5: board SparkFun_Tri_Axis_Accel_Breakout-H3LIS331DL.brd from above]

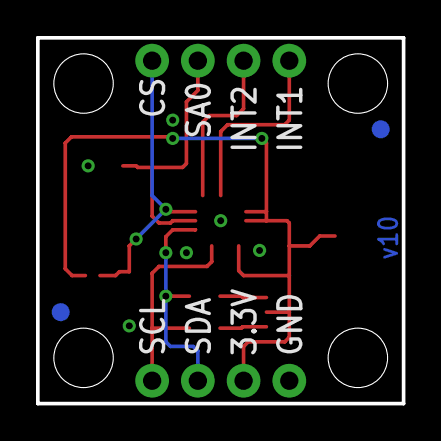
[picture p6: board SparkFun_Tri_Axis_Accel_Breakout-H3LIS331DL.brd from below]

Board: 2 copper layers, 20.3 x 20.3 mm, 23 parts (2 on the bottom side), 10 nets.

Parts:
C1: 10uF; EIA3216
C2: 0.1uF; 0603
FRAME1: FRAME-LETTER; CREATIVE_COMMONS
J1, J2: 1X04
JP1: JUMPER-SMT_3_2-NC_PASTE_NO-SILK; SMT-JUMPER_3_2-NC_PASTE_NO-SILK
JP2: JUMPER-SMT_2_NO_NO-SILK; SMT-JUMPER_2_NO_NO-SILK
JP3: JUMPER-SMT_2_NC_PASTE_NO-SILK; SMT-JUMPER_2_NC_PASTE_NO-SILK
JP4, JP5, JP6, JP7: FIDUCIAL1X2; FIDUCIAL-1X2
JP8, JP9, JP10, JP11: STAND-OFF
LOGO1: SFE_LOGO_FLAME.1_INCH; SFE_LOGO_FLAME_.1
LOGO2: OSHW-LOGOS; OSHW-LOGO-S
R1, R4: 10k; 0603
R2, R3: 4.7k; 0603
U1: H3LIS331DL; LGA-16-3X3

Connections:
3.3V: C1.+, C2.1, J2.2, JP1.2, JP3.2, R4.2, U1.1, U1.14, U1.15
CS: J1.4, JP3.1, R1.2, U1.8
GND: C1.-, C2.2, J2.1, JP2.1, R1.1, U1.5, U1.10, U1.12, U1.13, U1.16
INT1: J1.1, U1.11
INT2: J1.2, U1.9
unnamed: JP1.1, R3.1
unnamed: JP1.3, R2.1
SA0: J1.3, JP2.2, R4.1, U1.7
SCL: J2.4, R3.2, U1.4
SDA: J2.3, R2.2, U1.6

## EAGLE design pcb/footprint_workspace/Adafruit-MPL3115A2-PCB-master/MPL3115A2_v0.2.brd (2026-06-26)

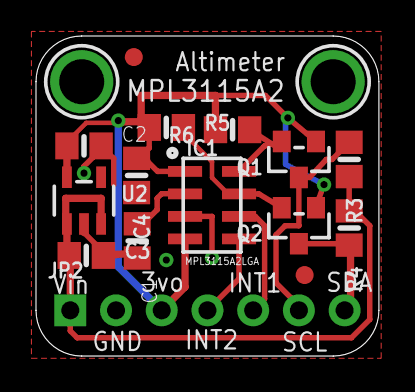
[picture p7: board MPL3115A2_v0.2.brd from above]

Board: 2 copper layers, 19.1 x 17.8 mm, 18 parts (1 on the bottom side), 10 nets.

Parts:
C1, C2: 0.1µF; 0805-NO
C3, C4: 10uF; 0805-NO
FID1, FID2: FIDUCIAL""; FIDUCIAL_1MM
IC1: MPL3115A2LGA; LGA8
JP2: 1X07_ROUND_70
Q1, Q2: BSS138; SOT23-WIDE
R3, R4, R5, R6: 10K; 0805-NO
U2: MIC5225-3.3; SOT23-5
U$8, U$9: MOUNTINGHOLE2.5; MOUNTINGHOLE_2.5_PLATED
U$14: ADAFRUIT_3.5MM

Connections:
+3V3: C2.1, C4.1, IC1.P$1, IC1.P$4, JP2.3, Q1.1, Q2.1, R5.1, R6.2, U2.5
+5V: C3.1, JP2.1, R3.2, R4.1, U2.1, U2.3
CAP: C1.1, IC1.P$2
GND: C1.2, C2.2, C3.2, C4.2, IC1.P$3, JP2.2, U2.2
INT1: IC1.P$6, JP2.5
INT2: IC1.P$5, JP2.4
SCL_3.3V: IC1.P$8, Q1.2, R6.1
SCL_5.0V: JP2.6, Q1.3, R3.1
SDA_3.3V: IC1.P$7, Q2.2, R5.2
SDA_5.0V: JP2.7, Q2.3, R4.2

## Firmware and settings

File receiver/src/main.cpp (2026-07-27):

#include <Arduino.h>
#include <SPI.h>

#include "board_pinmap.h"
#include "nura_constants.h"
#include "nura_protocol_v1_lite.h"

#define private public
#include <LoRa.h>
#undef private

namespace
{
constexpr unsigned long kSerialBaud = 115200UL;
#if defined(NURA_GROUND_SX1276)
constexpr long kLoraFrequencyHz = NuraConstants::LoRa::kFlightFrequencyHz;
#else
constexpr long kLoraFrequencyHz = 433000000L;
#endif
constexpr uint32_t kLoraSpiFrequencyHz = 125000UL;
constexpr uint8_t kLoraSsPin = 10U;
constexpr uint8_t kLoraResetPin = 9U;
constexpr int8_t kLoraLibraryResetPin = -1;
constexpr uint8_t kLoraDio0Pin = 2U;
constexpr uint8_t kLoraRxEnablePin = 4U;
constexpr uint8_t kLoraTxEnablePin = 3U;
constexpr int kLoraTxPowerDbm = 2;
constexpr int kLoraSpreadingFactor = 7;
constexpr long kLoraSignalBandwidthHz = 125000L;
constexpr int kLoraCodingRateDenominator = 5;
constexpr long kLoraPreambleLength = 8L;
constexpr int kLoraSyncWord = 0x12;
constexpr uint8_t kLoraRegVersion = 0x42U;
constexpr uint8_t kLoraRegRssiValue = 0x1BU;
constexpr int16_t kLoraHfRssiOffsetDbm = -157;
constexpr uint8_t kLoraExpectedVersion = 0x12U;
constexpr uint8_t kLoraInitAttempts = 5U;
constexpr uint32_t kRssiSampleIntervalMs = 5UL;

constexpr uint32_t kCommandRetryIntervalMs = 250UL;
constexpr uint8_t kCommandMaxAttempts = 8U;

#if defined(NURA_RECEIVER_AUTO_COMMAND_TEST)
constexpr bool kAutoCommandTestEnabled = true;
#else
constexpr bool kAutoCommandTestEnabled = false;
#endif

uint8_t selectedSpiMode = SPI_MODE0;
uint8_t selectedSpiModeNumber = 0U;
uint8_t lastMode0Version = 0U;
uint8_t lastMode1Version = 0U;
uint8_t lastMode2Version = 0U;
uint8_t lastMode3Version = 0U;
bool radioReady = false;
uint16_t uplinkFrameSeq = 0U;
uint16_t nextCommandSeq = 1U;
uint32_t fastRxCount = 0UL;
uint32_t gpsRxCount = 0UL;
uint32_t controlAckRxCount = 0UL;
uint32_t phyRxCount = 0UL;
uint32_t frameDecodeFailCount = 0UL;
bool forceDeployDone = false;
bool deprecatedAbortDone = false;
bool completionPrinted = false;
uint32_t forceDeployDoneMs = 0UL;
uint32_t lastStatusMs = 0UL;
uint32_t lastRssiSampleMs = 0UL;
int16_t currentRssiDbm = -200;
int16_t peakRssiDbm = -200;

struct PendingCommand
{
    bool active = false;
    uint8_t commandId = 0U;
    uint16_t commandSeq = 0U;
    uint16_t frameSeq = 0U;
    uint32_t nonce = 0UL;
    int16_t param0 = 0;
    int16_t param1 = 0;
    uint8_t attempts = 0U;
    uint32_t lastTxMs = 0UL;
};

PendingCommand pending;

void beginSpi()
{
    SPI.begin();
}

void configureRfSwitchForReceive()
{
#if defined(NURA_GROUND_SX1276)
    pinMode(kLoraRxEnablePin, OUTPUT);
    pinMode(kLoraTxEnablePin, OUTPUT);
    digitalWrite(kLoraTxEnablePin, LOW);
    digitalWrite(kLoraRxEnablePin, HIGH);
#endif
}

void printHexByte(uint8_t value)
{
    Serial.print("0x");
    if (value < 16U)
    {
        Serial.print('0');
    }
    Serial.print(value, HEX);
}

uint8_t readLoraRegisterRaw(uint8_t address, uint8_t spiMode)
{
    SPISettings settings(kLoraSpiFrequencyHz, MSBFIRST, spiMode);
    pinMode(kLoraSsPin, OUTPUT);
    digitalWrite(kLoraSsPin, HIGH);
    SPI.beginTransaction(settings);
    digitalWrite(kLoraSsPin, LOW);
    delayMicroseconds(20);
    SPI.transfer(address & 0x7FU);
    const uint8_t value = SPI.transfer(0x00U);
    delayMicroseconds(20);
    digitalWrite(kLoraSsPin, HIGH);
    SPI.endTransaction();
    return value;
}

void resetRadio()
{
    pinMode(kLoraSsPin, OUTPUT);
    digitalWrite(kLoraSsPin, HIGH);
    pinMode(kLoraResetPin, OUTPUT);
    digitalWrite(kLoraResetPin, LOW);
    delay(50);
    digitalWrite(kLoraResetPin, HIGH);
    delay(500);
}

bool beginRadio()
{
    LoRa.setPins(kLoraSsPin, kLoraLibraryResetPin, kLoraDio0Pin);
    LoRa.setSPIFrequency(kLoraSpiFrequencyHz);

    for (uint8_t attempt = 1U; attempt <= kLoraInitAttempts; ++attempt)
    {
        beginSpi();
        resetRadio();

        lastMode0Version = readLoraRegisterRaw(kLoraRegVersion, SPI_MODE0);
#if !defined(NURA_GROUND_SX1276)
        lastMode1Version = readLoraRegisterRaw(kLoraRegVersion, SPI_MODE1);
        lastMode2Version = readLoraRegisterRaw(kLoraRegVersion, SPI_MODE2);
        lastMode3Version = readLoraRegisterRaw(kLoraRegVersion, SPI_MODE3);
#endif

        Serial.print("init_attempt=");
        Serial.print(attempt);
        Serial.print(" m0=");
        printHexByte(lastMode0Version);
        Serial.print(" m1=");
        printHexByte(lastMode1Version);
        Serial.print(" m2=");
        printHexByte(lastMode2Version);
        Serial.print(" m3=");
        printHexByte(lastMode3Version);
        Serial.println();

#if defined(NURA_GROUND_SX1276)
        if (lastMode0Version == kLoraExpectedVersion)
        {
            selectedSpiMode = SPI_MODE0;
            selectedSpiModeNumber = 0U;
        }
        else
        {
            delay(250);
            continue;
        }
#else
        if (lastMode1Version == kLoraExpectedVersion)
        {
            selectedSpiMode = SPI_MODE1;
            selectedSpiModeNumber = 1U;
        }
        else if (lastMode0Version == kLoraExpectedVersion)
        {
            selectedSpiMode = SPI_MODE0;
            selectedSpiModeNumber = 0U;
        }
        else if (lastMode2Version == kLoraExpectedVersion)
        {
            selectedSpiMode = SPI_MODE2;
            selectedSpiModeNumber = 2U;
        }
        else if (lastMode3Version == kLoraExpectedVersion)
        {
            selectedSpiMode = SPI_MODE3;
            selectedSpiModeNumber = 3U;
        }
        else
        {
            delay(250);
            continue;
        }
#endif

        LoRa._spiSettings = SPISettings(kLoraSpiFrequencyHz, MSBFIRST, selectedSpiMode);
        Serial.print("selected_spi_mode=");
        Serial.println(selectedSpiModeNumber);
        Serial.print("library_reg_version=");
        printHexByte(LoRa.readRegister(kLoraRegVersion));
        Serial.println();

        if (LoRa.begin(kLoraFrequencyHz))
        {
            LoRa._spiSettings = SPISettings(kLoraSpiFrequencyHz, MSBFIRST, selectedSpiMode);
            LoRa.setTxPower(kLoraTxPowerDbm);
            LoRa.setSpreadingFactor(kLoraSpreadingFactor);
            LoRa.setSignalBandwidth(kLoraSignalBandwidthHz);
            LoRa.setCodingRate4(kLoraCodingRateDenominator);
            LoRa.setPreambleLength(kLoraPreambleLength);
            LoRa.setSyncWord(kLoraSyncWord);
            LoRa.enableCrc();
            LoRa.receive();
            return true;
        }

        LoRa.end();
        delay(250);
    }

    return false;
}

const char *flightStateName(uint8_t state)
{
    switch (state)
    {
    case nura::FLIGHT_INIT:
        return "INIT";
    case nura::FLIGHT_SAFE:
        return "SAFE";
    case nura::FLIGHT_ARMED:
        return "ARMED";
    case nura::FLIGHT_LAUNCH:
        return "LAUNCH";
    case nura::FLIGHT_COAST:
        return "COAST";
    case nura::FLIGHT_APOGEE:
        return "APOGEE";
    case nura::FLIGHT_DROGUE:
        return "DROGUE";
    case nura::FLIGHT_DEPLOY:
        return "DEPLOY";
    case nura::FLIGHT_GROUND:
        return "GROUND";
    case nura::FLIGHT_FAULT:
        return "FAULT";
    default:
        return "UNKNOWN";
    }
}

const char *commandName(uint8_t commandId)
{
    switch (commandId)
    {
    case nura::COMMAND_FORCE_DEPLOY_RECOVERY:
        return "FORCE_DEPLOY";
    case nura::COMMAND_ABORT_PROPULSION_DEPRECATED:
        return "ABORT_PROPULSION_DEPRECATED";
    case nura::COMMAND_SET_TELEMETRY_PROFILE:
        return "SET_TELEMETRY_PROFILE";
    default:
        return "UNKNOWN";
    }
}

const char *stageName(uint8_t stage)
{
    switch (stage)
    {
    case nura::ACK_RECEIVED:
        return "RECEIVED";
    case nura::ACK_ACCEPTED:
        return "ACCEPTED";
    case nura::ACK_EXECUTED:
        return "EXECUTED";
    case nura::ACK_REJECTED:
        return "REJECTED";
    case nura::ACK_DUPLICATE:
        return "DUPLICATE";
    default:
        return "UNKNOWN";
    }
}

const char *resultName(uint8_t result)
{
    switch (result)
    {
    case nura::RESULT_OK:
        return "OK";
    case nura::RESULT_AUTH_FAILED:
        return "AUTH_FAILED";
    case nura::RESULT_EXPIRED:
        return "EXPIRED";
    case nura::RESULT_BAD_FORMAT:
        return "BAD_FORMAT";
    case nura::RESULT_BAD_STATE:
        return "BAD_STATE";
    case nura::RESULT_NOT_ARMED:
        return "NOT_ARMED";
    case nura::RESULT_ALREADY_DONE:
        return "ALREADY_DONE";
    case nura::RESULT_NOT_SUPPORTED:
        return "NOT_SUPPORTED";
    case nura::RESULT_ACTUATOR_FAULT:
        return "ACTUATOR_FAULT";
    case nura::RESULT_INTERNAL_ERROR:
        return "INTERNAL_ERROR";
    default:
        return "UNKNOWN";
    }
}

const char *reasonName(uint8_t reason)
{
    switch (reason)
    {
    case nura::REJECT_NONE:
        return "NONE";
    case nura::REJECT_COMMAND_EXPIRED:
        return "COMMAND_EXPIRED";
    case nura::REJECT_UNKNOWN_COMMAND:
        return "UNKNOWN_COMMAND";
    case nura::REJECT_AUTH_TAG_MISMATCH:
        return "AUTH_TAG_MISMATCH";
    case nura::REJECT_DUPLICATE_OLDER_COMMAND:
        return "DUPLICATE_OLDER_COMMAND";
    case nura::REJECT_DEPLOYMENT_INHIBITED:
        return "DEPLOYMENT_INHIBITED";
    case nura::REJECT_CONTINUITY_BAD:
        return "CONTINUITY_BAD";
    case nura::REJECT_STATE_REJECTED:
        return "STATE_REJECTED";
    case nura::REJECT_DEPRECATED_COMMAND:
        return "DEPRECATED_COMMAND";
    case nura::REJECT_PROFILE_REJECTED:
        return "PROFILE_REJECTED";
    default:
        return "UNKNOWN";
    }
}

bool sendControlCommand(PendingCommand &cmd)
{
    nura::ControlPayload control;
    control.subtype = nura::CONTROL_CMD;
    control.commandId = cmd.commandId;
    control.commandSeq = cmd.commandSeq;
    control.nonce = cmd.nonce;
    control.validUntilMs = 0UL;
    control.param0 = cmd.param0;
    control.param1 = cmd.param1;
    nura::makeControlAuthTag(control,
                             cmd.frameSeq,
                             NuraConstants::Telemetry::kControlAuthKey,
                             control.authOrAck);

    uint8_t payload[nura::kControlPayloadLen];
    uint8_t frame[nura::kMaxFrameLen];
    nura::encodeControlPayload(control, payload, sizeof(payload));
    const size_t frameLen = nura::encodeFrame(nura::MESSAGE_CONTROL,
                                              NuraConstants::Telemetry::kVehicleId,
                                              cmd.frameSeq,
                                              nura::FrameDirection::UPLINK,
                                              NuraConstants::Telemetry::kControlAuthKey,
                                              payload,
                                              nura::kControlPayloadLen,
                                              frame,
                                              sizeof(frame));
    if (frameLen == 0U)
    {
        Serial.println("FAIL: control_encode");
        return false;
    }

    LoRa._spiSettings = SPISettings(kLoraSpiFrequencyHz, MSBFIRST, selectedSpiMode);
    LoRa.idle();
    delay(2);
    if (!LoRa.beginPacket())
    {
        LoRa.receive();
        Serial.println("FAIL: control_beginPacket");
        return false;
    }
    const size_t written = LoRa.write(frame, frameLen);
    const bool ok = written == frameLen && LoRa.endPacket() == 1;
    LoRa.receive();

    ++cmd.attempts;
    cmd.lastTxMs = millis();

    Serial.print("cmd tx command=");
    Serial.print(commandName(cmd.commandId));
    Serial.print(" command_seq=");
    Serial.print(cmd.commandSeq);
    Serial.print(" frame_seq=");
    Serial.print(cmd.frameSeq);
    Serial.print(" attempt=");
    Serial.print(cmd.attempts);
    Serial.print(" len=");
    Serial.println(frameLen);
    if (!ok)
    {
        Serial.println("FAIL: control_tx");
    }
    return ok;
}

void startCommand(uint8_t commandId, int16_t param0, int16_t param1)
{
    pending = PendingCommand{};
    pending.active = true;
    pending.commandId = commandId;
    pending.commandSeq = nextCommandSeq++;
    pending.frameSeq = uplinkFrameSeq++;
    pending.nonce = 0x4E550000UL ^ (static_cast<uint32_t>(pending.commandSeq) << 8) ^ millis();
    pending.param0 = param0;
    pending.param1 = param1;
    pending.lastTxMs = 0UL;
    pending.attempts = 0U;

    Serial.print("cmd start command=");
    Serial.print(commandName(commandId));
    Serial.print(" command_seq=");
    Serial.println(pending.commandSeq);
    sendControlCommand(pending);
}

void serviceCommandSender()
{
    if (!kAutoCommandTestEnabled)
    {
        return;
    }

    if (!pending.active)
    {
        if (!forceDeployDone && fastRxCount >= 10UL && gpsRxCount >= 1UL && millis() > 3000UL)
        {
            startCommand(nura::COMMAND_FORCE_DEPLOY_RECOVERY, 0, 0);
        }
        else if (forceDeployDone && !deprecatedAbortDone && (millis() - forceDeployDoneMs) > 1500UL)
        {
            startCommand(nura::COMMAND_ABORT_PROPULSION_DEPRECATED, 0, 0);
        }
        return;
    }

    if (pending.attempts >= kCommandMaxAttempts)
    {
        Serial.print("FAIL: command_timeout command=");
        Serial.print(commandName(pending.commandId));
        Serial.print(" command_seq=");
        Serial.println(pending.commandSeq);
        pending.active = false;
        return;
    }

    if ((millis() - pending.lastTxMs) >= kCommandRetryIntervalMs)
    {
        sendControlCommand(pending);
    }
}

void handleFast(const nura::ParsedFrame &frame)
{
    nura::FastTelemetry fast;
    if (!nura::decodeFastPayload(frame.payload, frame.payloadLen, fast))
    {
        Serial.println("FAIL: fast_decode");
        return;
    }
    ++fastRxCount;

    const uint8_t stateCode = nura::flightStateFromStatus(fast.statusWord);
    const float accelXG = static_cast<float>(fast.lowAccelXCg) * 0.01f;
    const float accelYG = static_cast<float>(fast.lowAccelYCg) * 0.01f;
    const float accelZG = static_cast<float>(fast.lowAccelZCg) * 0.01f;
    const float gyroXDps = static_cast<float>(fast.gyroXDps10) * 0.1f;
    const float gyroYDps = static_cast<float>(fast.gyroYDps10) * 0.1f;
    const float gyroZDps = static_cast<float>(fast.gyroZDps10) * 0.1f;

    Serial.print("rx type=FAST seq=");
    Serial.print(frame.seq);
    Serial.print(" boot_ms=");
    Serial.print(static_cast<unsigned long>(fast.bootMs));
    Serial.print(" state=");
    Serial.print(flightStateName(stateCode));
    Serial.print(" state_code=");
    Serial.print(stateCode);
    Serial.print(" status=0x");
    if (fast.statusWord < 0x1000U)
    {
        Serial.print('0');
    }
    if (fast.statusWord < 0x0100U)
    {
        Serial.print('0');
    }
    if (fast.statusWord < 0x0010U)
    {
        Serial.print('0');
    }
    Serial.print(fast.statusWord, HEX);
    Serial.print(" baro_dp_2pa=");
    Serial.print(fast.baroDp2Pa);
    Serial.print(" accel_g=(");
    Serial.print(accelXG, 2);
    Serial.print(',');
    Serial.print(accelYG, 2);
    Serial.print(',');
    Serial.print(accelZG, 2);
    Serial.print(')');
    Serial.print(" gyro_dps=(");
    Serial.print(gyroXDps, 1);
    Serial.print(',');
    Serial.print(gyroYDps, 1);
    Serial.print(',');
    Serial.print(gyroZDps, 1);
    Serial.print(')');
    Serial.print(" batt_mv=");
    Serial.print(fast.battMv);
    Serial.print(" health=");
    Serial.print((fast.statusWord & nura::STATUS_LOW_IMU_OK) != 0U ? "imu" : "-");
    Serial.print(',');
    Serial.print((fast.statusWord & nura::STATUS_BARO_OK) != 0U ? "baro" : "-");
    Serial.print(',');
    Serial.print((fast.statusWord & nura::STATUS_GPS_OK) != 0U ? "gps" : "-");
    Serial.print(',');
    Serial.print((fast.statusWord & nura::STATUS_RADIO_OK) != 0U ? "radio" : "-");
    Serial.print(" rssi=");
    Serial.print(LoRa.packetRssi());
    Serial.print(" snr=");
    Serial.println(LoRa.packetSnr());
}

void handleGps(const nura::ParsedFrame &frame)
{
    nura::GpsTelemetry gps;
    if (!nura::decodeGpsPayload(frame.payload, frame.payloadLen, gps))
    {
        Serial.println("FAIL: gps_decode");
        return;
    }
    ++gpsRxCount;

    const double latitudeDeg = static_cast<double>(gps.latitudeE7) * 0.0000001;
    const double longitudeDeg = static_cast<double>(gps.longitudeE7) * 0.0000001;
    const float altitudeM = static_cast<float>(gps.gpsAltDm) * 0.1f;
    const float speedMps = static_cast<float>(gps.speedCms) * 0.01f;
    const float courseDeg = static_cast<float>(gps.courseCdeg) * 0.01f;
    const float hdop = static_cast<float>(gps.hdopX10) * 0.1f;
    const float ageS = static_cast<float>(gps.age100Ms) * 0.1f;

    Serial.print("rx type=GPS seq=");
    Serial.print(frame.seq);
    Serial.print(" fix=");
    Serial.print((gps.fixFlags & 0x02U) != 0U ? "yes" : "no");
    Serial.print(" lat_e7=");
    Serial.print(static_cast<long>(gps.latitudeE7));
    Serial.print(" lon_e7=");
    Serial.print(static_cast<long>(gps.longitudeE7));
    Serial.print(" lat_deg=");
    Serial.print(latitudeDeg, 7);
    Serial.print(" lon_deg=");
    Serial.print(longitudeDeg, 7);
    Serial.print(" alt_m=");
    Serial.print(altitudeM, 1);
    Serial.print(" speed_mps=");
    Serial.print(speedMps, 2);
    Serial.print(" course_deg=");
    Serial.print(courseDeg, 2);
    Serial.print(" hdop=");
    Serial.print(hdop, 1);
    Serial.print(" sats=");
    Serial.print(gps.satellites);
    Serial.print(" age_s=");
    Serial.print(ageS, 1);
    Serial.print(" rssi=");
    Serial.print(LoRa.packetRssi());
    Serial.print(" snr=");
    Serial.println(LoRa.packetSnr());
}

void handleControl(const nura::ParsedFrame &frame)
{
    nura::ControlPayload control;
    if (!nura::decodeControlPayload(frame.payload, frame.payloadLen, control))
    {
        Serial.println("FAIL: control_decode");
        return;
    }
    if (control.subtype != nura::CONTROL_ACK)
    {
        return;
    }

    ++controlAckRxCount;
    const uint8_t stage = control.authOrAck[0];
    const uint8_t result = control.authOrAck[1];
    const uint8_t reason = control.authOrAck[2];

    Serial.print("rx type=CONTROL subtype=ACK command=");
    Serial.print(commandName(control.commandId));
    Serial.print(" command_seq=");
    Serial.print(control.commandSeq);
    Serial.print(" frame_seq=");
    Serial.print(frame.seq);
    Serial.print(" stage=");
    Serial.print(stageName(stage));
    Serial.print(" result=");
    Serial.print(resultName(result));
    Serial.print(" reason=");
    Serial.println(reasonName(reason));

    if (!pending.active ||
        control.commandSeq != pending.commandSeq ||
        control.commandId != pending.commandId ||
        control.nonce != pending.nonce)
    {
        return;
    }

    if (pending.commandId == nura::COMMAND_FORCE_DEPLOY_RECOVERY &&
        stage == nura::ACK_EXECUTED &&
        result == nura::RESULT_OK)
    {
        forceDeployDone = true;
        forceDeployDoneMs = millis();
        pending.active = false;
        Serial.println("PASS: force_deploy_ack_executed");
    }
    else if (pending.commandId == nura::COMMAND_ABORT_PROPULSION_DEPRECATED &&
             stage == nura::ACK_REJECTED &&
             result == nura::RESULT_NOT_SUPPORTED)
    {
        deprecatedAbortDone = true;
        pending.active = false;
        Serial.println("PASS: deprecated_abort_rejected");
    }
    else if (stage == nura::ACK_REJECTED)
    {
        pending.active = false;
    }
}
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
void loop()
{
    const uint32_t nowMs = millis();
    if (radioReady && (nowMs - lastRssiSampleMs) >= kRssiSampleIntervalMs)
    {
        lastRssiSampleMs = nowMs;
        currentRssiDbm = kLoraHfRssiOffsetDbm +
                         static_cast<int16_t>(LoRa.readRegister(kLoraRegRssiValue));
        if (currentRssiDbm > peakRssiDbm)
        {
            peakRssiDbm = currentRssiDbm;
        }
    }

    if ((nowMs - lastStatusMs) >= 1000UL)
    {
        lastStatusMs = nowMs;
        Serial.print("status radio=");
        Serial.print(radioReady ? "ready" : "not_ready");
        Serial.print(" spi_mode=");
        Serial.print(selectedSpiModeNumber);
        Serial.print(" m0=");
        printHexByte(lastMode0Version);
        Serial.print(" m1=");
        printHexByte(lastMode1Version);
        Serial.print(" m2=");
        printHexByte(lastMode2Version);
        Serial.print(" m3=");
        printHexByte(lastMode3Version);
        Serial.print(" phy_rx=");
        Serial.print(phyRxCount);
        Serial.print(" decode_fail=");
        Serial.print(frameDecodeFailCount);
        Serial.print(" rssi_now_dbm=");
        Serial.print(currentRssiDbm);
        Serial.print(" rssi_peak_dbm=");
        Serial.print(peakRssiDbm);
        Serial.println();
        peakRssiDbm = currentRssiDbm;
    }

    if (!radioReady)
    {
        return;
    }

    receiveFrames();
    serviceCommandSender();
    printCompletionIfReady();
}

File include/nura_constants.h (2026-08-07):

#pragma once

#include <stdint.h>

#if __has_include("nura_radio_secrets.h")
#include "nura_radio_secrets.h"
#define NURA_RADIO_IDENTITY_PROVISIONED 1
#else
#define NURA_RADIO_VEHICLE_ID 0x4E555241UL
#define NURA_RADIO_AUTH_KEY_BYTES                                              \
    0x4e, 0x55, 0x52, 0x41, 0x2d, 0x56, 0x31, 0x4c,                         \
        0x49, 0x54, 0x45, 0x2d, 0x54, 0x45, 0x53, 0x54
#define NURA_RADIO_IDENTITY_PROVISIONED 0
#endif

namespace NuraConstants
{
namespace Physics
{
constexpr float kGravityMps2 = 9.80665f;
constexpr float kRadToDeg = 57.2957795f;
constexpr float kDegToRad = 0.0174532925f;
} // namespace Physics

namespace Atmosphere
{
constexpr float kSeaLevelPressurePa = 101325.0f;
constexpr float kStandardAtmosphereMeters = 44330.0f;
constexpr float kPressureExponent = 0.19029495f;
constexpr float kInversePressureExponent = 5.255f;
} // namespace Atmosphere

namespace App
{
constexpr unsigned long kSerialBaudRate = 115200UL;
constexpr uint16_t kFaultBlinkIntervalMs = 1000U;
constexpr uint32_t kBoardPowerSettleDelayMs = 5000UL;
constexpr uint32_t kBusSettleDelayMs = 250UL;
} // namespace App

namespace Sensors
{
constexpr uint8_t kSensorInitRetryAttempts = 5U;
constexpr uint32_t kSensorInitRetryDelayMs = 150UL;
constexpr uint8_t kImuReadFailureThreshold = 3U;
constexpr uint8_t kImuMaxRecoveryAttempts = 5U;
constexpr uint32_t kImuRecoveryIntervalMs = 1000UL;
constexpr uint32_t kImuTaskPeriodMs = 10UL;
constexpr uint32_t kMagnetometerTaskPeriodMs = 100UL;
constexpr uint32_t kBarometerTaskPeriodMs = 50UL;
constexpr uint32_t kBarometerRecoveryIntervalMs = 1000UL;
constexpr uint8_t kBarometerMedianWindowSamples = 3U;
constexpr float kBarometerAltitudeLpfAlpha = 0.35f;
constexpr uint32_t kBarometerStaleFaultMs = 300UL;
constexpr uint8_t kBarometerConsecutiveReadFailFault = 5U;
constexpr uint8_t kBarometerBadValueTotalFault = 10U;
constexpr uint8_t kBarometerBadValueConsecutiveFault = 5U;
constexpr float kBarometerMinAltitudeAglM = -200.0f;
constexpr float kBarometerMaxAltitudeAglM = 5000.0f;
constexpr uint32_t kBarometerStuckWindowMs = 5000UL;
constexpr float kBarometerStuckRangeM = 0.2f;
constexpr float kTiltMinAccelNormG = 0.2f;
constexpr float kTiltMaxAccelNormG = 3.0f;
constexpr float kAttitudeAccelCorrectionMinNormG = 0.7f;
constexpr float kAttitudeAccelCorrectionMaxNormG = 1.3f;
constexpr float kAttitudeAccelCorrectionGain = 0.8f;
constexpr uint32_t kAttitudeMaxDeltaMs = 100UL;
constexpr uint32_t kGnssTaskPeriodMs = 50UL;
constexpr uint16_t kGnssPollByteBudget = 256U;
constexpr uint16_t kGnssSerialRxBufferBytes = 1024U;
constexpr uint32_t kGnssMaxFixAgeMs = 2000UL;
constexpr uint32_t kLowGSampleLogIntervalMs = 1000UL;
constexpr uint32_t kHighGSampleLogIntervalMs = 1000UL;
constexpr uint32_t kPowerSenseTaskPeriodMs = 100UL;
constexpr uint16_t kPowerSenseAdcReferenceMv = 3300U;
constexpr uint8_t kPowerSenseAdcResolutionBits = 10U;
constexpr uint16_t kPowerSenseDividerRatioNumerator = 5545U;
constexpr uint16_t kPowerSenseDividerRatioDenominator = 1000U;
constexpr uint16_t kPowerSenseExpectedMinBatteryMv = 11100U;
constexpr uint16_t kPowerSenseExpectedMaxBatteryMv = 12600U;
constexpr uint16_t kPowerSenseExpectedMinRawAdc = 620U;
constexpr uint16_t kPowerSenseExpectedMaxRawAdc = 704U;
constexpr uint16_t kPowerSenseMinValidBatteryMv = 6000U;
constexpr uint16_t kPowerSenseMaxValidBatteryMv = 14000U;
} // namespace Sensors

namespace Tasks
{
constexpr uint32_t kWatchdogTaskPeriodMs = 50UL;
constexpr uint32_t kFlightStateTaskPeriodMs = 10UL;
constexpr uint32_t kLoggerTaskPeriodMs = 20UL;
constexpr uint32_t kTelemetryTaskPeriodMs = 20UL;
} // namespace Tasks

namespace Logger
{
constexpr uint8_t kDrainBudget = 4U;
constexpr uint8_t kOutputFailThreshold = 3U;
constexpr uint8_t kSdInitRetryAttempts = 20U;
constexpr uint32_t kSdInitRetryDelayMs = 250UL;
constexpr uint16_t kFlightLogRamBufferBytes = 16U * 1024U;
constexpr uint16_t kFlightLogStorageQueueBytes = 8U * 1024U;
constexpr uint32_t kFlightLogQspiFlashBytes = 16UL * 1024UL * 1024UL;
constexpr uint16_t kFlightLogQspiPageBytes = 256U;
constexpr uint16_t kFlightLogQspiEraseSectorBytes = 4U * 1024U;
constexpr uint8_t kFlightLogQspiEraseAheadSectors = 2U;
constexpr uint32_t kFlightLogQspiInitEraseTimeoutUs = 500000UL;
constexpr uint32_t kFlightLogQspiProgramTimeoutUs = 10000UL;
constexpr uint32_t kFlightLogQspiIpCommandTimeoutUs = 1000UL;
constexpr uint32_t kFlightLogSdPreallocateBytes = 16UL * 1024UL * 1024UL;
constexpr uint16_t kFlightLogSdSectorBytes = 512U;
constexpr uint32_t kFlightLogSdBusyTimeoutMs = 1200UL;
constexpr uint16_t kFlightLogFastPeriodMs = 20U;
constexpr uint16_t kFlightLogSlowPeriodMs = 100U;
constexpr uint8_t kFlightLogDrainRecordsPerTick = 8U;
constexpr uint8_t kFlightDecisionTraceQueueDepth = 16U;
constexpr uint8_t kFlightStateTransitionQueueDepth = 16U;
} // namespace Logger
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

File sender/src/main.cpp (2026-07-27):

#include <Arduino.h>
#include <SPI.h>

#include "board_pinmap.h"
#include "nura_constants.h"
#include "nura_protocol_v1_lite.h"

#define private public
#include <LoRa.h>
#undef private

namespace
{
constexpr unsigned long kSerialBaud = 115200UL;
#if defined(NURA_SENDER_SPARKFUN_SX1276_BENCH)
constexpr long kLoraFrequencyHz = 922300000L;
constexpr uint32_t kLoraSpiFrequencyHz = 250000UL;
constexpr int kLoraTxPowerDbm = 2;
#else
constexpr long kLoraFrequencyHz = 433000000L;
constexpr uint32_t kLoraSpiFrequencyHz = 125000UL;
constexpr int kLoraTxPowerDbm = 2;
#endif
constexpr int kLoraSpreadingFactor = 7;
constexpr long kLoraSignalBandwidthHz = 125000L;
constexpr int kLoraCodingRateDenominator = 5;
constexpr int kLoraSyncWord = 0x12;
constexpr uint8_t kLoraRegVersion = 0x42U;
constexpr uint8_t kLoraExpectedVersion = 0x12U;
constexpr uint8_t kLoraInitAttempts = 5U;

constexpr uint32_t kFastIntervalMs = 200UL;
constexpr uint32_t kGpsIntervalMs = 1000UL;

uint8_t selectedSpiMode = SPI_MODE0;
uint8_t selectedSpiModeNumber = 0U;
bool radioReady = false;
uint16_t downlinkSeq = 0U;
uint32_t lastFastMs = 0UL;
uint32_t lastGpsMs = 0UL;
bool deployFired = false;

SPIClass &loraSpi()
{
#if defined(NURA_SENDER_SPARKFUN_SX1276_BENCH)
    return SPI1;
#else
    return SPI;
#endif
}

uint8_t loraMosiPin()
{
#if defined(NURA_SENDER_SPARKFUN_SX1276_BENCH)
    return BoardPinMap::Spi1Bus::mosiPin;
#else
    return BoardPinMap::SpiBus::mosiPin;
#endif
}

uint8_t loraMisoPin()
{
#if defined(NURA_SENDER_SPARKFUN_SX1276_BENCH)
    return BoardPinMap::Spi1Bus::misoPin;
#else
    return BoardPinMap::SpiBus::misoPin;
#endif
}

uint8_t loraSckPin()
{
#if defined(NURA_SENDER_SPARKFUN_SX1276_BENCH)
    return BoardPinMap::Spi1Bus::sckPin;
#else
    return BoardPinMap::SpiBus::sckPin;
#endif
}

void setRfPath(bool receivePath, bool transmitPath)
{
#if defined(NURA_SENDER_SPARKFUN_SX1276_BENCH)
    digitalWrite(BoardPinMap::Sx1276BreakoutLoRa::rxEnablePin, receivePath ? HIGH : LOW);
    digitalWrite(BoardPinMap::Sx1276BreakoutLoRa::txEnablePin, transmitPath ? HIGH : LOW);
#else
    (void)receivePath;
    (void)transmitPath;
#endif
}

struct AckQueue
{
    nura::ControlPayload items[4];
    uint8_t head = 0U;
    uint8_t count = 0U;

    bool push(const nura::ControlPayload &item)
    {
        if (count >= 4U)
        {
            return false;
        }
        const uint8_t index = static_cast<uint8_t>((head + count) % 4U);
        items[index] = item;
        ++count;
        return true;
    }

    bool pop(nura::ControlPayload &out)
    {
        if (count == 0U)
        {
            return false;
        }
        out = items[head];
        head = static_cast<uint8_t>((head + 1U) % 4U);
        --count;
        return true;
    }
};

AckQueue ackQueue;

struct RecentCommand
{
    bool valid = false;
    uint8_t commandId = 0U;
    uint16_t commandSeq = 0U;
    uint32_t nonce = 0UL;
};

RecentCommand recentCommands[4];
uint8_t recentCommandWriteIndex = 0U;

void beginSpi()
{
#if defined(CORE_TEENSY)
    loraSpi().setMOSI(loraMosiPin());
    loraSpi().setMISO(loraMisoPin());
    loraSpi().setSCK(loraSckPin());
#endif
    loraSpi().begin();
}

void printHexByte(uint8_t value)
{
    Serial.print("0x");
    if (value < 16U)
    {
        Serial.print('0');
    }
    Serial.print(value, HEX);
}

uint8_t readLoraRegisterRaw(uint8_t address, uint8_t spiMode)
{
    SPISettings settings(kLoraSpiFrequencyHz, MSBFIRST, spiMode);
    pinMode(BoardPinMap::Ra01DevelopmentLoRa::ssPin, OUTPUT);
    digitalWrite(BoardPinMap::Ra01DevelopmentLoRa::ssPin, HIGH);
    loraSpi().beginTransaction(settings);
    digitalWrite(BoardPinMap::Ra01DevelopmentLoRa::ssPin, LOW);
    delayMicroseconds(20);
    loraSpi().transfer(address & 0x7FU);
    const uint8_t value = loraSpi().transfer(0x00U);
    delayMicroseconds(20);
    digitalWrite(BoardPinMap::Ra01DevelopmentLoRa::ssPin, HIGH);
    loraSpi().endTransaction();
    return value;
}

void resetRadio()
{
    pinMode(BoardPinMap::Ra01DevelopmentLoRa::ssPin, OUTPUT);
    digitalWrite(BoardPinMap::Ra01DevelopmentLoRa::ssPin, HIGH);
    pinMode(BoardPinMap::Ra01DevelopmentLoRa::resetPin, OUTPUT);
    digitalWrite(BoardPinMap::Ra01DevelopmentLoRa::resetPin, LOW);
    delay(50);
    digitalWrite(BoardPinMap::Ra01DevelopmentLoRa::resetPin, HIGH);
    delay(500);
}
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

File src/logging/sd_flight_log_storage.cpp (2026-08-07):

#include "sd_flight_log_storage.h"

#include <stdio.h>
#include <string.h>

#include "logging/flight_log_record.h"
#include "nura_constants.h"

namespace
{
uint8_t digit(char value)
{
    return value >= '0' && value <= '9' ? static_cast<uint8_t>(value - '0') : 0U;
}

uint8_t compileMonth()
{
    static constexpr char kMonths[] = "JanFebMarAprMayJunJulAugSepOctNovDec";
    for (uint8_t month = 0U; month < 12U; ++month)
    {
        if (strncmp(__DATE__, kMonths + (month * 3U), 3U) == 0)
        {
            return static_cast<uint8_t>(month + 1U);
        }
    }
    return 1U;
}

uint8_t compileDay()
{
    const uint8_t day = static_cast<uint8_t>(digit(__DATE__[4]) * 10U + digit(__DATE__[5]));
    return day == 0U ? 1U : day;
}

uint16_t compileYear()
{
    return static_cast<uint16_t>(digit(__DATE__[7]) * 1000U +
                                 digit(__DATE__[8]) * 100U +
                                 digit(__DATE__[9]) * 10U +
                                 digit(__DATE__[10]));
}

uint8_t compileHour()
{
    return static_cast<uint8_t>(digit(__TIME__[0]) * 10U + digit(__TIME__[1]));
}

uint8_t compileMinute()
{
    return static_cast<uint8_t>(digit(__TIME__[3]) * 10U + digit(__TIME__[4]));
}

uint8_t compileSecond()
{
    return static_cast<uint8_t>(digit(__TIME__[6]) * 10U + digit(__TIME__[7]));
}

void buildDateTime(uint16_t *date, uint16_t *time)
{
    if (date != nullptr)
    {
        *date = FS_DATE(compileYear(), compileMonth(), compileDay());
    }
    if (time != nullptr)
    {
        *time = FS_TIME(compileHour(), compileMinute(), compileSecond());
    }
}
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

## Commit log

2026-04-08 Reformat codes and switch environment to nano
2026-04-09 Purge legacy sensor stack for architecture reset
    [avionics.kicad_pcb, avionics.kicad_sch]
2026-04-09 feat: add MPU6050 HAL and IMU sensor task
2026-04-09 feat: improve runtime health handling for imu, logger, and scheduler
2026-04-09 wip: added failure detection and recovery watchdog task
    [imu_task.cpp, main.cpp]
2026-05-05 port on teensy4.1
2026-05-12 add sensor calibration logic on hal && calibration demand on sensors.md
2026-05-13 add uniform sensor test (not included proj. target)
2026-05-13 lora unit test complete. (근데 사실 패킷구조 정의 이런건 하나도 안함... ㅎㅎ) 그냥 잘 돌아가는데까지 어마무시한 시간이 걸렸습니다. 이제 전압 플로팅같은건 없이 안정화는 되었으니깐, 패킷구조 정의할거구요, 나머지 로직도 짤거에요. 참고로 그냥 LORA.h 기본파일 쓰면 안되고 mode bit 수정해야 잘되네요?? 하하 샤갈
2026-05-14 add AGENTS.md document 폴더 만들고 센서랑 요구사항들도 추가했어
    [2026 전자팀요구사항.csv, NURA 자체 요구사항.csv]
2026-05-14 sensor_test 추가했어요. HAL 만들기 전에 센서 테스트한 코드는 여기다가 임시로 올리시면 됩니다.
2026-05-15 Add SPI H3LIS331DL high-g IMU module
2026-05-17 09fcc77까지 fast-forward, lora update
2026-05-18 0518 - 모든 센서 테스트 및 HAL, state, fc 통합 완료
2026-05-21 비행 로직넣을때 (의도하지않은)AI에 의한 추가방지 지침 추가, 로직 추가 시 문서화 필수조건 설
2026-05-23 상태머신 로직추가 및 테스트 로직 업그레이
    [summary.csv]
2026-05-23 소스코드 내 모든 상수 단일 파일로 분
2026-05-23 Grounding status 수정
2026-05-24 baro fault 감지 및 실시 드로그 로직(IMU기반) 추가
2026-05-25 IMU fault 로직 추가
2026-05-29 Fix LoRa pair test tooling
    [main.cpp]
2026-05-29 Fix macOS Teensy bootloader upload
2026-05-29 flash 로직추가 (미완)
2026-05-30 로거 완성 + 기말고사전까지 쉬다올게요
2026-06-22 실기판기반 핀맵수정 & 로거로직추가 & 파이로 로직추가 & 버저 구현 추가 & 배터리 전압 체킹 및 변환 로직추가 & pcb lora sx1276으로 변
    [battery_voltage_hal.h, board_pinmap.h, fsm_task.h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]
2026-06-22 통신을 위한 시도
2026-06-23 blocking I/O 전부 non-blocking으로 수정, 로라 안정성 체크
    [high_g_imu_task.cpp, imu_task.cpp, magnetometer_task.cpp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]
2026-06-23 init fail 로직수정
2026-06-25 레거시 hal제거, 파이로2번 간섭으로 임시 비활성화,pcb업로
2026-06-26 시험발사용 프로젝트 fork 추가
2026-06-26 만능기판용 땜빵코드 추가
    [MPL3115A2_v0.2.brd, MPL3115A2_v0.2.kicad_pcb, MPL3115A2_v0.2.kicad_sch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]
2026-07-12 Revert "first commit"
    This reverts commit 9fd41f29da68658a2734bea50716e110a1a671d1.
    [2026 전자팀요구사항.csv, NURA 자체 요구사항.csv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]
2026-07-12 Reapply "first commit"
    This reverts commit 29a84f1e4f7dcf39e06b48659da01041f1638a82.
    [2026 전자팀요구사항.csv, NURA 자체 요구사항.csv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]
2026-07-20 Sync current avionics and PCB updates
    [MPL3115A2_v0.2.brd, MPL3115A2_v0.2.kicad_pcb, MPL3115A2_v0.2.kicad_sch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]
2026-07-26 HWE 문제 해결완
2026-07-27 Add bench FSM reset uplink
    [fsm_task.h, mosfet_pyro_hal.cpp, nura_constants.h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]
2026-08-05 GPS baud rate 관련 수
    [260627_fsw_apogee_prediction.xlsx]
2026-08-06 Add bench serial FSM control (s/a/z commands)
    - Line-based serial commands in debug_no_lora env (NURA_BENCH_SERIAL_COMMANDS)
    - s: advance flight FSM state, a/z: bump bench accel +-0.5G, h: help
    - Bench accel injected via consumeFlightAccelSample(), real IMU untouched
    - Ignore host modem-manager chatter (exact 1-char lines only)
    Ultraworked with [Sisyphus](https://github.com/code-yeongyu/oh-my-openagent)
2026-08-06 Add GPS baud probe and live sensor monitor tools
    - gps_baud_probe_main.cpp: sweep GPS baud rates to find lock
    - gps_fix_monitor_main.cpp: watch NMEA fix status live
    - live_sensor_monitor_main/output: stream IMU/GPS/sensor values over serial
    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

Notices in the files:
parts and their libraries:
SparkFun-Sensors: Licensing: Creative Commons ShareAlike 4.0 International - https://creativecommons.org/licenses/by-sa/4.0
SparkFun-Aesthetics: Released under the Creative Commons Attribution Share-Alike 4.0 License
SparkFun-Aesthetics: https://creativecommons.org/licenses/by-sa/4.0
